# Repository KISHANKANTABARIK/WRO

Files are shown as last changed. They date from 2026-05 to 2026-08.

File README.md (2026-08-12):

# Engineering Documentation - Team DeusMachina

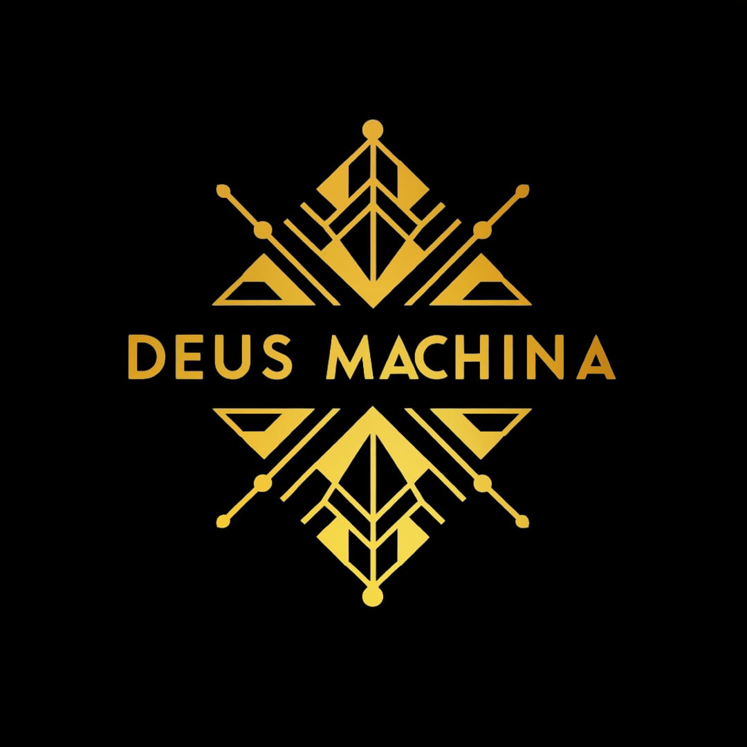
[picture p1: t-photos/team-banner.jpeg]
Team Banner


## Introduction

In this repository you will find all the information related to the construction, design, and programming of the autonomous robot built by *Team DeusMachina* for the  Future Engineers category in the 2026 Season.
This has been an incredible journey with a lot of obstacles, and we have done our best to come up with a design that we were not only satisfied with, but one that could properly accomplish all of the objectives present in this edition of the competition.

## Contents

- [Team Members](#team-members)
- [Hardware Design](#hardware-design)
  * [Design Process](#design-process)
  * [Assembly Process](#assembly-process)
  * [Elements](#elements)
    + [3D Printed](#3d-printed)
    + [Electronics](#electronics)
- [Software Design](#software-design)
  * [Image and Sensor Processing](#image-and-sensor-processing)
    + [Image Capturing](#image-capturing)
    + [Processing Pipeline](#processing-pipeline)
    + [Distance / Position Detection](#distance--position-detection)
  * [Robot Movement](#robot-movement)
    + [Steering / Servo Configuration](#steering--servo-configuration)
    + [Robot Orientation](#robot-orientation)
    + [Route Determination](#route-determination)
  * [Data Sending](#data-sending)
- [Impact](#impact)
- [Our Journey](#our-journey)

---

# Team Members

[#team-members](#team-members)

- **[Kishan Kanta Barik]**:

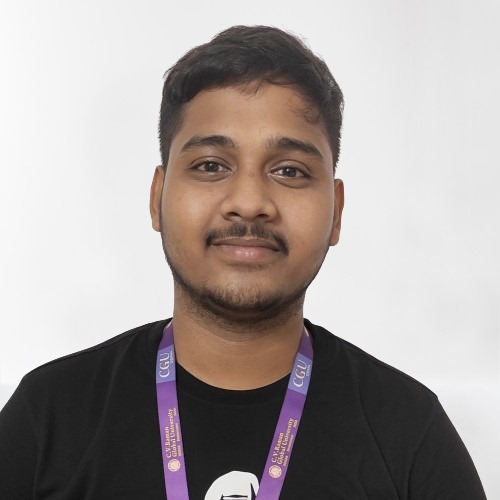
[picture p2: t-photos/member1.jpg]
Member 1 photo

> Hi, my name is Kishan Kanta Barik. I'm part of Team DeusMachina and I'm responsible for ROS2 Architecture & Embedded C . 

- **[Swastik Prasad Behera]**:

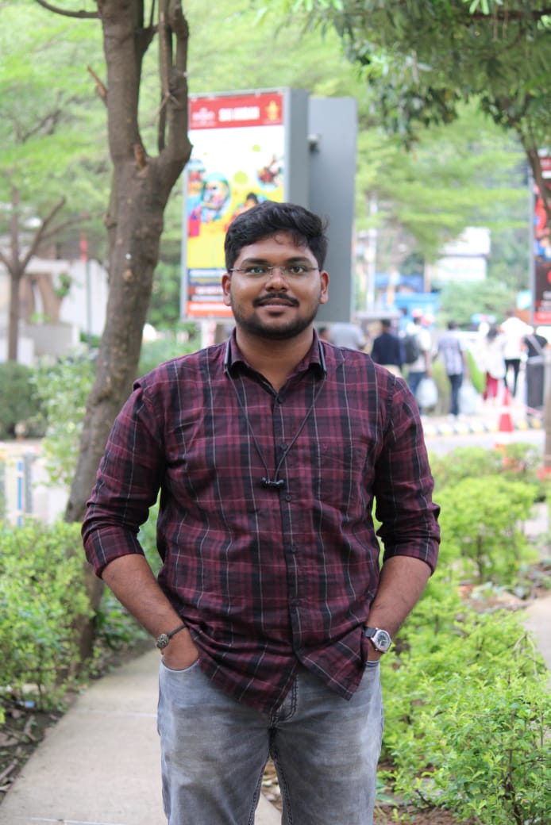
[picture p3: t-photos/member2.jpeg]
Member 2 photo

> Hello, I am Swastik Prasad Behera. I am the team's Designer and I'm responsible for Mechanical Designing and Assembly.

- **[Mohit Kumar Bera]**:

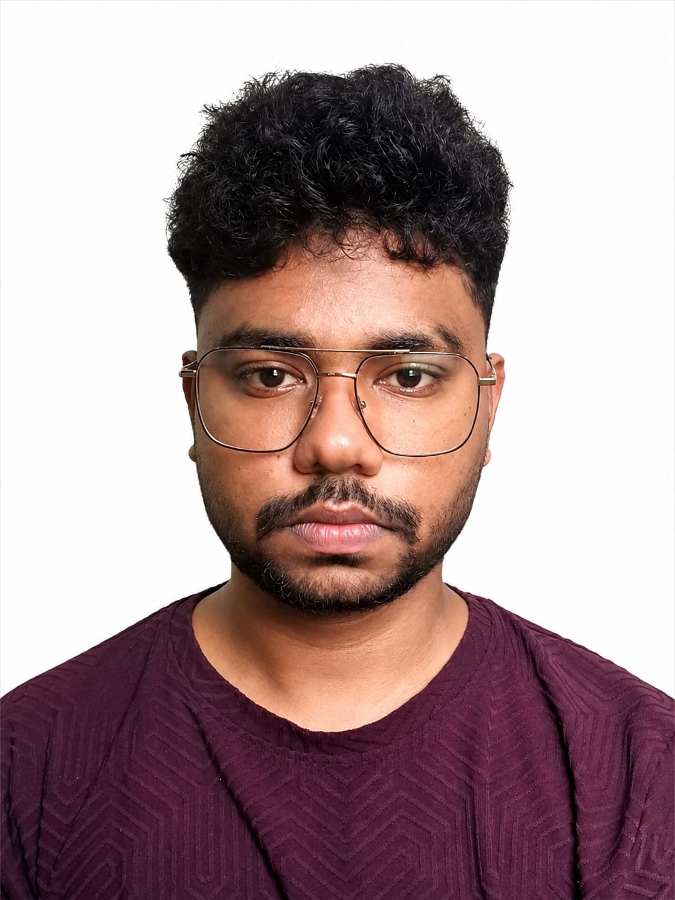
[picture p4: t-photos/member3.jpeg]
Mohit Kumar Bera

> I am Mohit Kumar Bera, the team's Electronics Engineering. I am in charge of Electronics circuits and wiring. 

- **[Achirangshu Patra ]**:

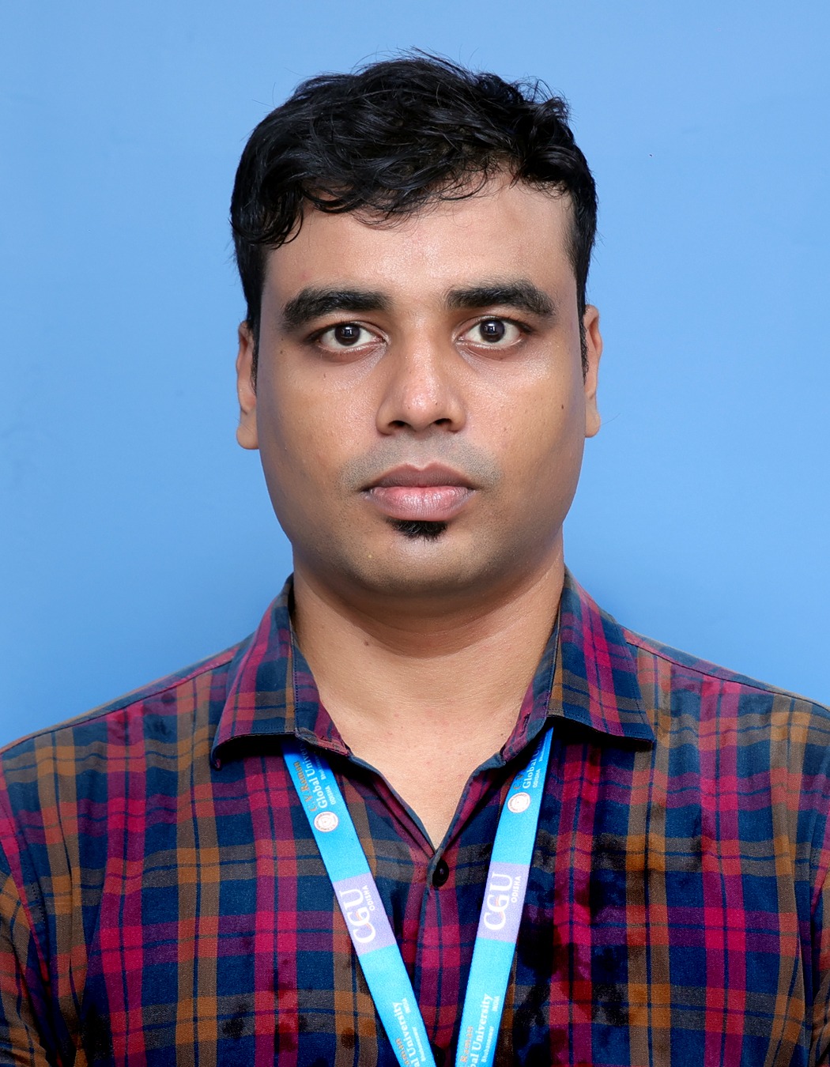
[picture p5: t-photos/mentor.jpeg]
Mentor photo

> Hi, my name is Achirangshu Patra . I have received the B.Tech. degree in Electrical Engineering from Budge Budge Institute of Technology, West Bengal, India, the Post Diploma in Industrial Automation and Robotics from MSME CTTC, Bhubaneswar, India, and the M.Tech. degree in Mechatronics Engineering from C.V. Raman Global University, Odisha, India. He also received the Post Graduate Certificate in Artificial Intelligence and Its Applications under the AICTE QIP program from the Indian Institute of Technology Kharagpur, India. He is currently pursuing the Ph.D. degree in federated unlearning for privacy-preserving machine learning in distributed edge systems at C.V. Raman Global University, where he is also an Assistant Professor and heads the Mitsubishi Electric Authorized Training Centre. He has conducted industrial training and technical workshops for professionals, faculty members, university and school students, covering industrial automation, PLC, HMI, drives, robotics, mechatronics, and Industry 4.0 technologies, with participants from organizations including JPL, JSP, Tata Motors, and other industrial institutions. He has served as a Jury Member for the India Skills National and Regional Competitions and as a WorldSkills Mentor for Industrial Control and Industry 4.0. He also mentors students in various technical competitions and hackathons, including the Mitsubishi Electric Cup, Janatics Automation Skill Challenge, and Smart India Hackathon, supporting students in project development, innovation, and competitive technical skills. His research interests include federated learning, machine unlearning, differential privacy, privacy-preserving edge intelligence, industrial automation, and intelligent cyber-physical systems. 

---

# Hardware Design

## Drivetrain Selection: All-Wheel Drive (4WD) — Single-Motor Dual-Differential System

### Design Overview

Unlike a conventional 4WD setup that uses one motor per axle or per wheel, our robot uses a **single central motor driving all four wheels through a two-differential, single-axle transmission system**. This keeps the drivetrain compact, reduces the number of motors (and therefore the current draw and control complexity), while still delivering torque to all four wheels.

### How the System Works

1. **Motor & Central Gearbox** — A single DC gear motor is mounted in-line with a central gearbox/transfer case (the black housing in the middle of the assembly). This gearbox receives the motor's output and reduces/redirects it into a longitudinal drive path.

2. **Central Driveshaft** — From the gearbox, a single output shaft (the long center driveshaft) runs the length of the chassis, connecting the front and rear ends of the drivetrain. This shaft is what allows one motor to power both axles simultaneously, similar in principle to a propeller shaft in a full-size AWD vehicle.

3. **Dual Differential Units** — At each end of the central driveshaft sits a **bevel-gear differential** (the two purple/magenta gear clusters — one front, one rear). Each differential takes the rotational input from the central shaft and splits it 90° outward to the left and right wheel axles on that end.

4. **Differential Function** — Because each end has its own differential, the left and right wheels on that axle can rotate at slightly different speeds during a turn (standard differential behavior), preventing wheel scrub while still keeping both wheels driven — something a solid/fixed axle can't do.

5. **Half-Shafts to Wheels** — From each differential, a short half-shaft (with a universal/CV-style joint visible in the model) transmits power outward to each wheel hub, ending in a hex adapter for the wheel.

### Why This Configuration

- **Single point of power input** — only one motor needs to be controlled, driven, and powered, which simplifies the motor driver wiring and current budgeting compared to a 4-motor independent-wheel setup.
- **True mechanical AWD** — because power is split at the differential (not electronically per motor), all four wheels stay mechanically synchronized, avoiding the wheel-speed mismatches that can occur with independently controlled motors that aren't perfectly tuned to each other.
- **Weight and space savings** — replacing 3–4 motors with one central motor and a geared/shaft transmission frees up space and mass elsewhere in the chassis for electronics, sensors, and battery placement.
- **Consistent traction front and rear** — since both axles are driven from the same source through matched differentials, torque delivery to the front and rear wheels stays proportional, improving stability under acceleration and through corners.

### Trade-offs

- **Mechanical complexity** — two differentials plus a central driveshaft and multiple universal joints introduce more moving/wearing parts than a single-motor RWD or independent-motor 4WD setup, and require tighter manufacturing/assembly tolerances (gear mesh, shaft alignment).
- **No independent wheel control** — because all wheels are mechanically linked through one motor, the robot cannot apply differential torque electronically (e.g., for skid-steer-style turning assistance); steering must still be handled entirely by the separate front Ackermann steering system.
- **Single point of failure** — if the motor, central gearbox, or driveshaft fails, the entire drivetrain is disabled, unlike a multi-motor 4WD where one motor failure might still leave partial mobility.
- **Assembly precision** — bevel gear differentials need careful backlash tuning; too much play causes drivetrain slop, too little causes binding and excess motor load.

### Comparison with Common WRO Drive Systems

Most WRO Future Engineers teams use one of a handful of drivetrain patterns. Here's how our AWD choice stacks up against the alternatives most commonly seen in the competition:

| Drive System | How it Works | Pros | Cons | Typical WRO Use |
|---|---|---|---|---|
| **Rear-Wheel Drive (RWD)** — *most common in WRO* | A single motor (often a "hex"/gear motor) drives the rear axle; front wheels are steered via a servo through an Ackermann linkage and are not powered. | Simple, lightweight, cheap, few failure points, easy to tune and repair mid-competition. | Less traction on low-grip surfaces or sharp accelerations; all propulsion load falls on two wheels. | The default choice for the large majority of Future Engineers robots, including earlier iterations of our own robot (see [Design Process](#design-process)). |
| **Front-Wheel Drive (FWD)** | A single motor drives the front (steered) axle. | Simplifies packaging when the drive motor and steering share the front module. | Steering geometry becomes more complex (powered + steered wheels); traction can suffer when weight shifts rearward under acceleration. | Rare in WRO — most teams avoid combining steering and driving on the same axle due to added mechanical complexity. |
| **All-Wheel Drive (4WD)** — *our system* | Torque delivered to all four wheels, either through a differential + shaft or independent motors per wheel/axle, while front wheels still steer via Ackermann linkage or independent steering. | Best traction and acceleration consistency; more even load distribution; more resistant to wheel-slip on debris or uneven mats. | Heavier, higher current draw, more complex wiring/mechanical design, more to debug. | Used by a minority of teams, usually those prioritizing consistent lap times over simplicity, or where the track surface/rules reward extra grip. |
| **Skid-Steer / Differential Drive (2WD, no Ackermann)** | Two independently driven wheels (usually rear or side pairs) with passive casters or a fixed axle; turning is achieved by varying wheel speed rather than steering angle. | Mechanically simple, no steering linkage needed, sharp/zero-radius turns possible. | Not Ackermann-compliant, causes wheel scrub, and is generally disallowed or heavily penalized for realism in Future Engineers, which expects car-like steering. | Essentially not used in Future Engineers (more common in other WRO categories like RoboMission); mentioned here only for contrast. |

1. **[Change 1 — e.g. Motor upgrade]**: Explain the problem with the old approach and why the new component/approach was chosen.

Design change 1

2. **[Change 2 — e.g. Wheel replacement]**: Explain the reasoning.

Design change 2

3. **[Change 3 — e.g. Component reorganization]**: Explain the reasoning.

Design change 3

Describe the final architecture (e.g. modular design with distinct functional layers):

> Example: *The final design of the robot is intended as a modular design, consisting of N modules: [module 1 name/purpose], [module 2 name/purpose], [module 3 name/purpose]. This makes it easier to make repairs or replace/rearrange parts.*

Final structure

Link to the full 3D model/CAD files:
[3D design files](./models)

## Assembly Process

Walk through how the robot was physically assembled, module by module or subsystem by subsystem. Include any problems encountered during assembly/testing and how they were solved (e.g. sensor placement issues, interference, structural weaknesses).

Include a wiring/assembly diagram if available:

Assembly diagram

## Elements

### 3D Printed

> **Note:** State your print settings here (material, layer height, infill %, etc.)

- **[Part Name 1]**: Description of its function.

Part 1

- **[Part Name 2]**: Description of its function.

Part 2

- **[Part Name 3]**: Description of its function.

Part 3

*(Add one entry per printed part — chassis, brackets, sensor mounts, covers, etc.)*

### Electronics

For each component, include a short description of its role and a spec box.

- **[Component 1 — e.g. Motor Driver]**: Role in the robot.

Component 1

> **Specifications**
> - Spec 1
> - Spec 2
> - Spec 3

- **[Component 2 — e.g. Drive Motor]**: Role in the robot.

Component 2

> **Specifications**
> - Spec 1
> - Spec 2
> - Spec 3

- **[Component 3 — e.g. Steering Servo]**: Role in the robot.

- **[Component 4 — e.g. Raspberry pi4 - Module B (4GB Ram)]**: Main Micro Processor.

- **[Component 5 — e.g. STM32466RE]**: Secondary microcontroller.

- **[Component 6 — e.g. 2D 360 degree Lidar ]**: To measure and detect the object distance and real time objects.

- **[Component 7 — e.g. Camera]**: Identify the colour of th object.

- **[Component 8 — e.g. Batteries]**: Power source of the vehicle.

*(Add/remove entries to match your actual bill of materials.)*

---

# Software Design

## Image and Sensor Processing

### Image Capturing

Describe how frames/images are captured (camera model, resolution, library used, e.g. OpenCV) and at what stage in the pipeline this happens.

### Processing Pipeline

Describe your detection/processing pipeline step by step (e.g. color space conversion, masking, contour detection). Include representative code snippets:

```python
# Example: HSV threshold values for detection
lower_bound_1 = np.array([H_min, S_min, V_min], np.uint8)
upper_bound_1 = np.array([H_max, S_max, V_max], np.uint8)
```

Processing example

### Distance / Position Detection

Explain how the robot determines distance/position of detected objects relative to itself (e.g. dividing the frame into zones, using sensor fusion, etc.)

Position detection diagram

## Robot Movement

### Steering / Servo Configuration

Describe how the steering mechanism is controlled (pin assignments, control functions/library calls) and how sensor input maps to steering commands.

### Robot Orientation

Describe how the robot determines and maintains its orientation/heading (e.g. based on first detected turn direction, gyroscope, encoders).

### Route Determination

Describe the logic that decides the robot's path (e.g. based on detected color/marker, sensor readings, or map data) and how that decision is communicated between subsystems.

## Data Sending

Describe the communication protocol between your controllers/boards (e.g. I2C, UART, SPI) — include the libraries used, addressing, and wiring (e.g. SDA, SCL, GND for I2C).

```python
# Example: initializing I2C communication
import smbus
bus = smbus.SMBus(1)
I2C_ADDRESS = 0x08
```

---

# Impact

Reflect on the goals of the project, the skills your team developed (technical and non-technical), and the challenges you overcame. This section should convey the learning outcomes and personal/team growth from the project.

---

# Our Journey

Tell your team's story: how you got started, key milestones, competitions attended, results achieved, and what you're aiming for next. This is the narrative/human section of the documentation — make it personal.

---

# Thank You. Team DeusMachina - 2026.

## Repository Structure

```
.
├── models/         # 3D design/CAD files
├── other/          # Miscellaneous supporting files
├── schemes/        # Diagrams, wiring schematics, flowcharts
├── src/            # Source code (robot firmware/software)
├── t-photos/       # Team photos
├── v-photos/       # Vehicle/robot photos
├── videos/         # Demonstration videos
├── README.md       # This file
└── Team-Report_[Competition-Name].pdf   # Official team report
```

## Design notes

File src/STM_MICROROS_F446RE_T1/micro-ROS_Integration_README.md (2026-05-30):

# 🤖 micro-ROS on STM32 (FreeRTOS Node)

> **Bridging a bare-metal FreeRTOS motor controller to a ROS 2 Humble network using micro-ROS and a Raspberry Pi.**

This architecture replaces the raw UART string parser with a native micro-ROS node. The STM32 subscribes directly to ROS 2 topics (`/drive_motor_speed`, `/servo_angle`) and funnels the integers straight into the existing FreeRTOS hardware queues.

---

## 📋 Architecture

```
[ Raspberry Pi 4 ]                 [ STM32 Nucleo-F446RE ]
ROS 2 Humble                       FreeRTOS + micro-ROS

$ ros2 topic pub ────(USB)────> [ it_transport.c ] ──> [ microROS_Task ]
/drive_motor_speed                                         │
                                                           ├──> [ DCQueue ]
                                                           └──> [ ServoQueue ]
```

## 🛠️ Critical CubeMX Configurations

To prevent the STM32 from freezing on boot when running micro-ROS, these specific settings must be applied in `.ioc`:

1. **SysTick Conflict:** FreeRTOS must use `TIM1` as its Timebase Source (System Core -> SYS).
2. **Memory Starvation:** The `microROS_Task` stack size must be increased from 128 words to **`3000`** words (Middleware -> FREERTOS).
3. **Interrupt Transport:** `USART2 global interrupt` MUST be checked in the NVIC settings to allow the Pi to handshake with the STM32.

---

## 🚨 Integration Challenges & Fixes

### 1. Linker Error: "Multiple Definition of..."
* **Cause:** Copying `it_transport.c` or memory allocator `.c` files directly into `Core/Src` while simultaneously telling the compiler to build the `extra_sources` folder. The compiler builds two copies of the same functions.
* **Fix:** Delete the duplicates from `Core/Src`. Ensure you only unlock the `extra_sources` folder and uncheck "Exclude from build" for `it_transport.c` specifically.

### 2. Phantom Error: "Build Failed" (But the .elf is generated)
* **Cause:** The Eclipse-based IDE misinterprets a standard warning (`_gettimeofday is not implemented`) as a fatal error.
* **Fix:** If the `arm-none-eabi-size` table prints in the console showing the memory footprint, the code **did** compile successfully. Ignore the "Build Failed" text and flash the board.

### 3. Agent Stuck on "running..." (No Session Established)
* **Cause A (Handshake Timeout):** The STM32 booted too fast and the Pi was not ready, or the ping timeout was too aggressive.
  * **Fix:** Change the ping loop to `rmw_uros_ping_agent(1000, 1)` (1000ms timeout). Press the physical **RESET** button on the STM32 *after* the agent says `running...`.
* **Cause B (Missing Allocators):** FreeRTOS crashed because micro-ROS tried to use standard `malloc()`.
  * **Fix:** Ensure the custom allocators (`microros_allocate`, etc.) are defined and linked via `rcutils_set_default_allocator(&freeRTOS_allocator);` before the ping loop starts.

### 4. Agent Crash: "Serial Port Not Found, Error 2"
* **Cause:** You pressed the RESET button on the Nucleo board while the Agent was actively streaming data. This briefly cuts power to the ST-Link USB chip, causing Linux to lose the `/dev/ttyACM0` mount.
* **Fix:** Restart the Agent command on the Pi.

## 🚀 Running the Node

1. Flash the STM32 and plug it into the Pi via USB.
2. On the Pi, source the workspace: `source ~/microros_ws/install/local_setup.bash`
3. Start the agent: `ros2 run micro_ros_agent micro_ros_agent serial --dev /dev/ttyACM0 -b 115200 -v6`
4. Press RESET on the STM32. Wait for `Session established`.
5. In a new terminal, drive the robot:
   `ros2 topic pub --once /drive_motor_speed std_msgs/msg/Int32 "{data: 25000}"`

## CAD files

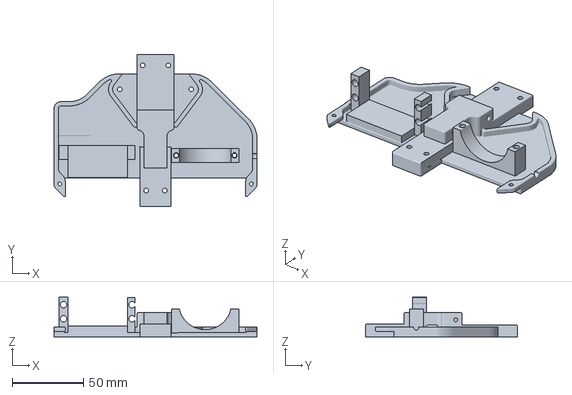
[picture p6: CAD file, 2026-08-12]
models/Chassis/chassis-front.3mf
142.4 x 106.8 x 28.0 mm

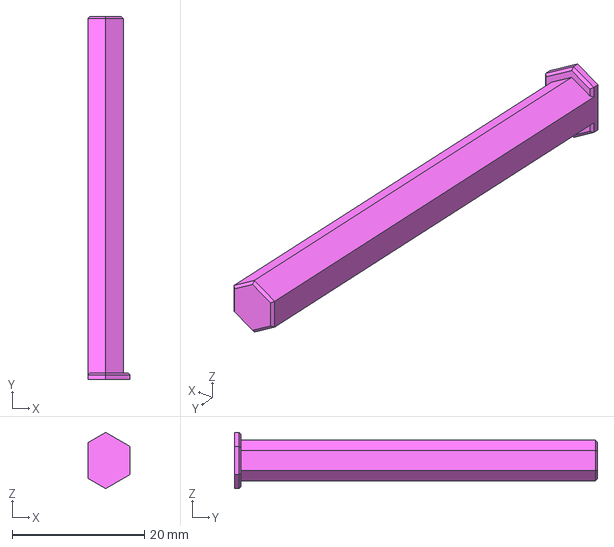
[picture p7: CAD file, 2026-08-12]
models/Drive/Center/center-shaft-rear.3mf
6.37 x 54.9 x 8.51 mm

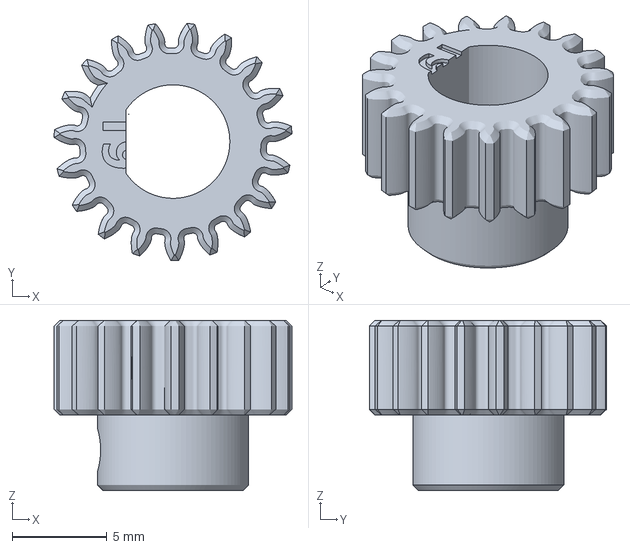
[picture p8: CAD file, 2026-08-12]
models/Drive/Center/Gears/pinion-06module-19T.3mf
12.6 x 12.6 x 9.00 mm

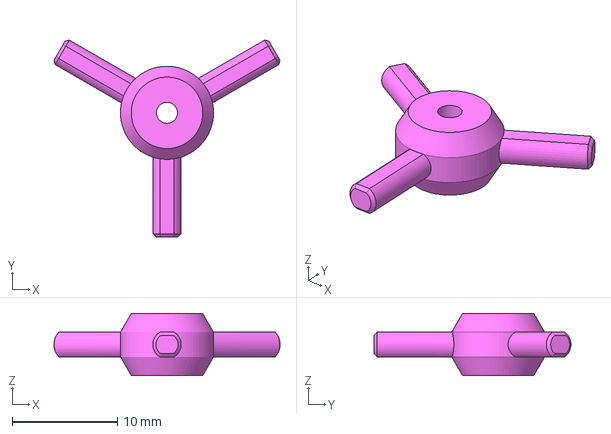
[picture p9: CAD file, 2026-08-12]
models/Drive/Differential Unit Front/Differential Gears/diff-gear-shaft.3mf
21.5 x 18.7 x 5.90 mm

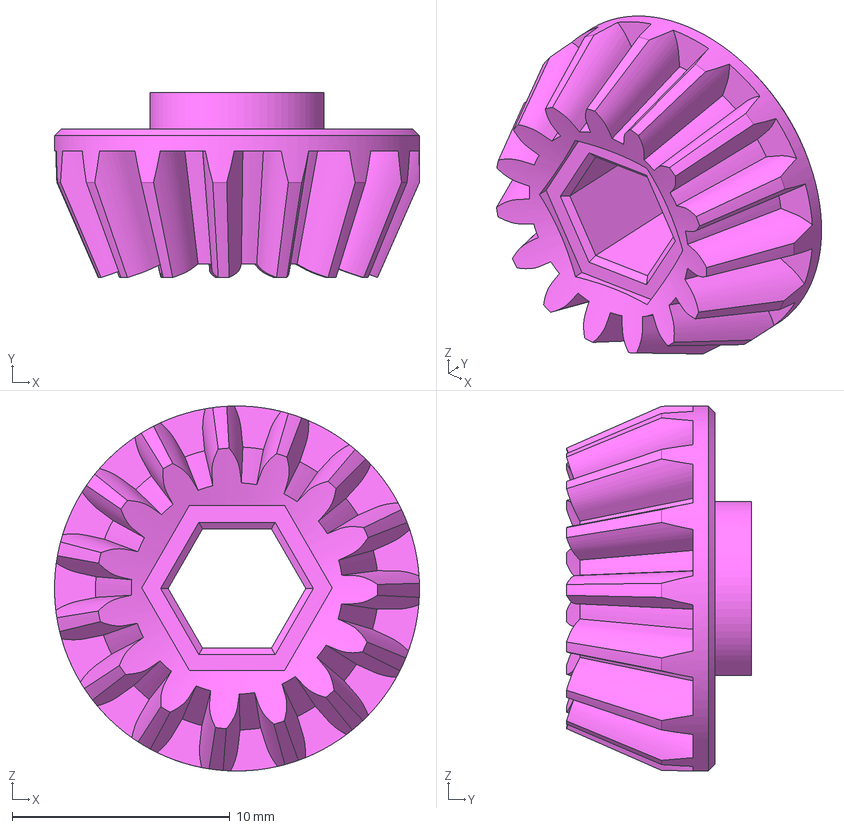
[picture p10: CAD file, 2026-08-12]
models/Drive/Differential Unit Front/Drive Gear/drive-gear-A.3mf
16.7 x 8.49 x 16.7 mm

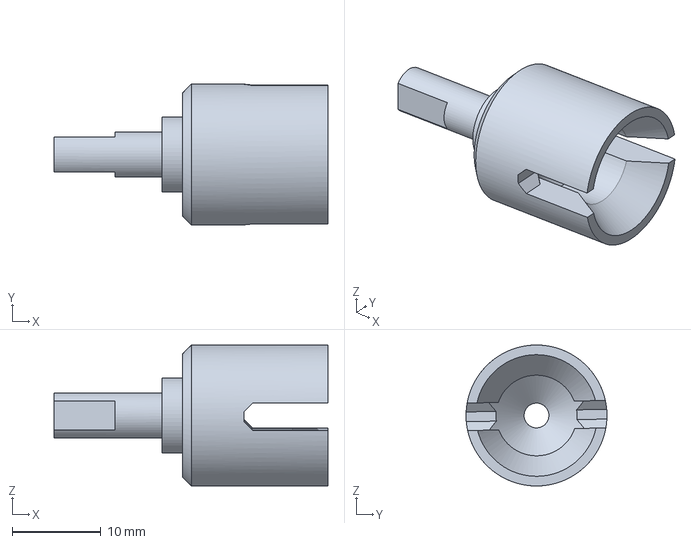
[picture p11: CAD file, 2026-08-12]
models/Drive/Differential Unit Front/Driver Cup/drive-cup-A.3mf
30.9 x 15.9 x 15.9 mm

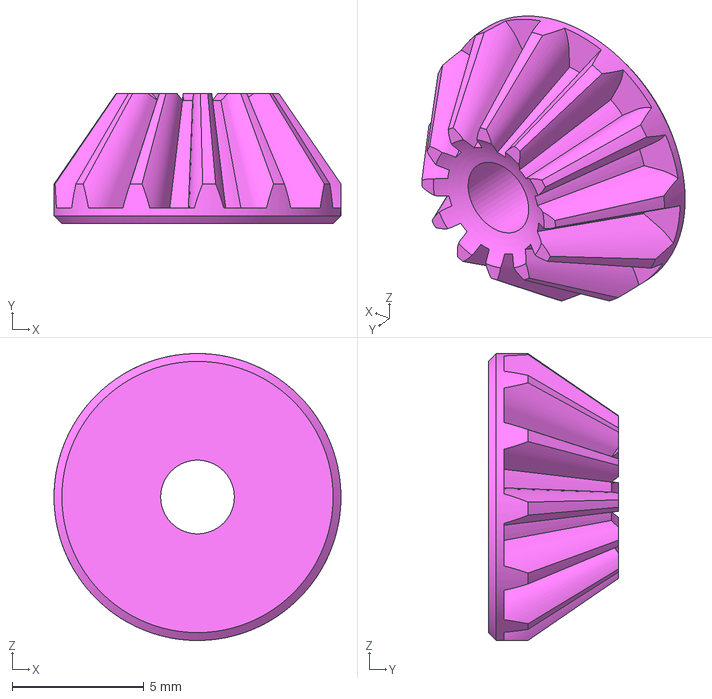
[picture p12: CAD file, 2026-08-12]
models/Drive/Differential Unit Rear/Differential Unit/diff-gear-C_2.3mf
10.9 x 4.95 x 10.9 mm

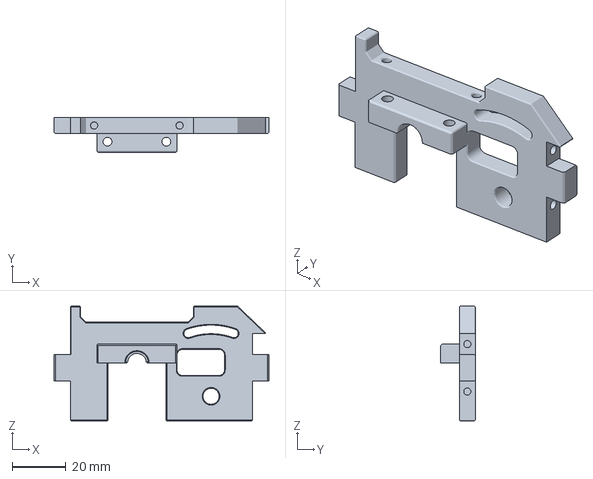
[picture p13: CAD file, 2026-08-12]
models/Drive/Motor Mount/motor-mount-B.3mf
80.4 x 13.0 x 42.9 mm

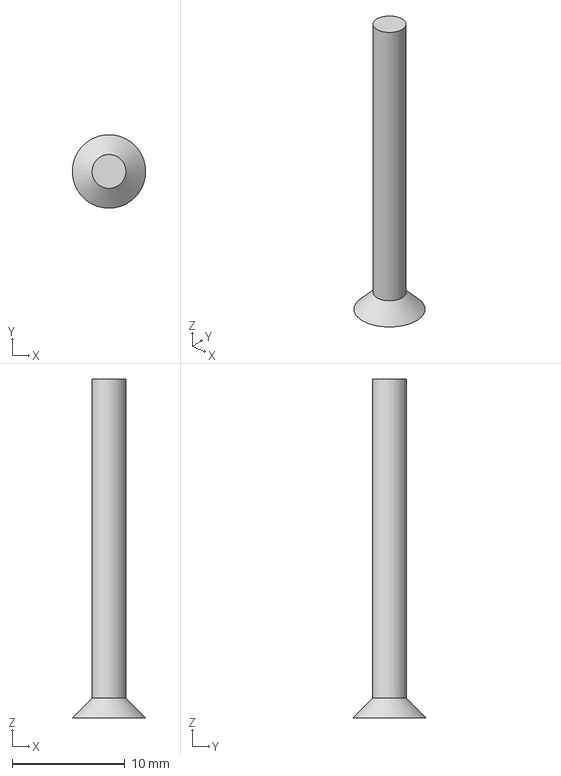
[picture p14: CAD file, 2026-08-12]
models/Drive/Wheel Axle Unit_4_units/FHCS-M3-30.3mf
6.50 x 6.50 x 30.0 mm

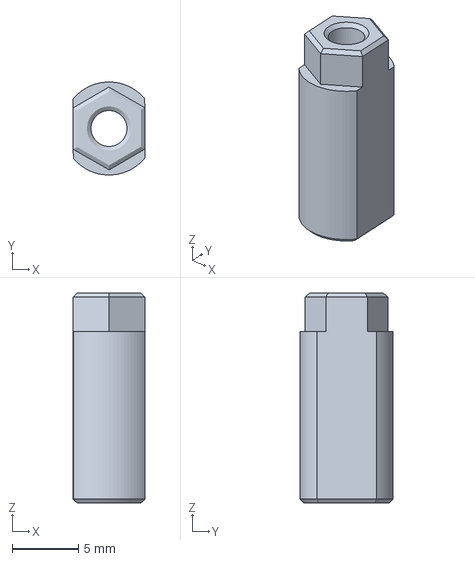
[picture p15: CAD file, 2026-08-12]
models/Front Assymble/Front Gearbox/front-steering-arm-post.3mf
5.42 x 7.00 x 15.8 mm

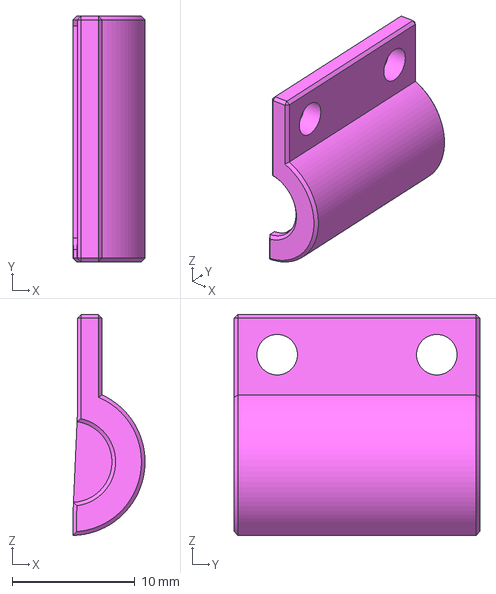
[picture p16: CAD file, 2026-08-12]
models/Front Assymble/Front Suspension/ESE Rotary Dampers/ese-rotary-damper-R-B2.3mf
5.88 x 20.0 x 18.0 mm

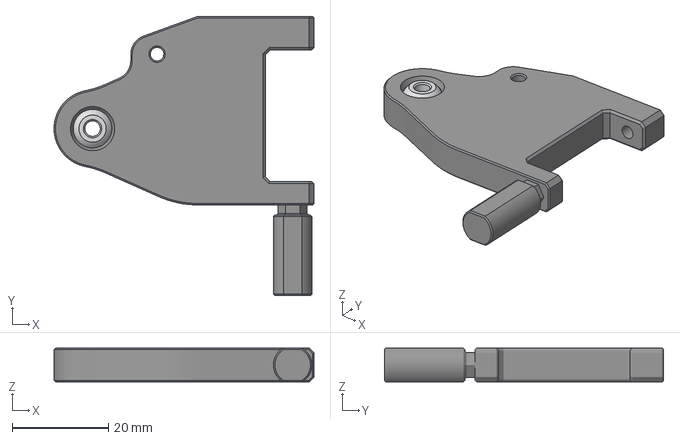
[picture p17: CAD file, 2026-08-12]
models/Front Assymble/Front Suspension/Front Suspension Lower/front-sus-lower-arm-A (Print_2).3mf
53.9 x 57.9 x 7.00 mm

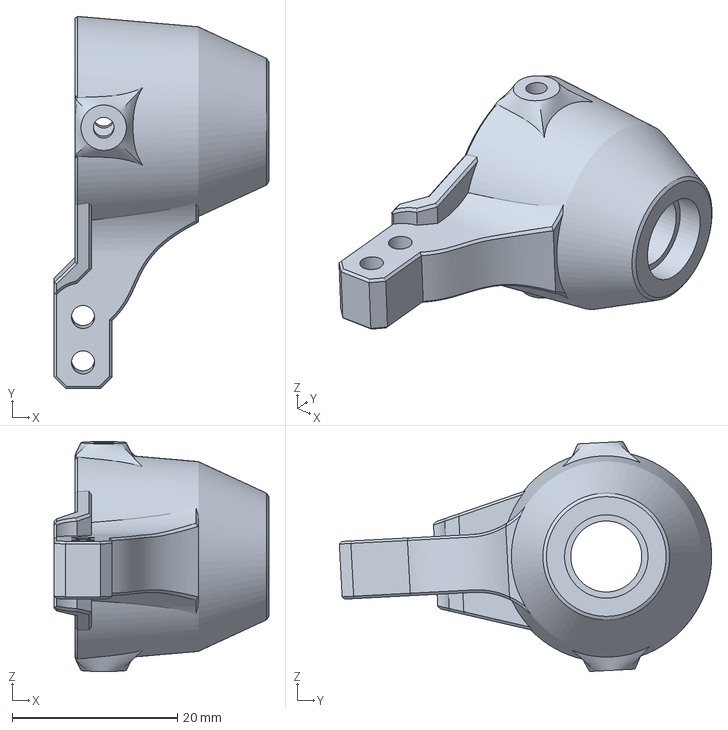
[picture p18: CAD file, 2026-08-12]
models/Front Assymble/Front Suspension/Front Suspension Uplight_Print_2_Each/front-sus-uplight.3mf
26.0 x 45.1 x 27.8 mm

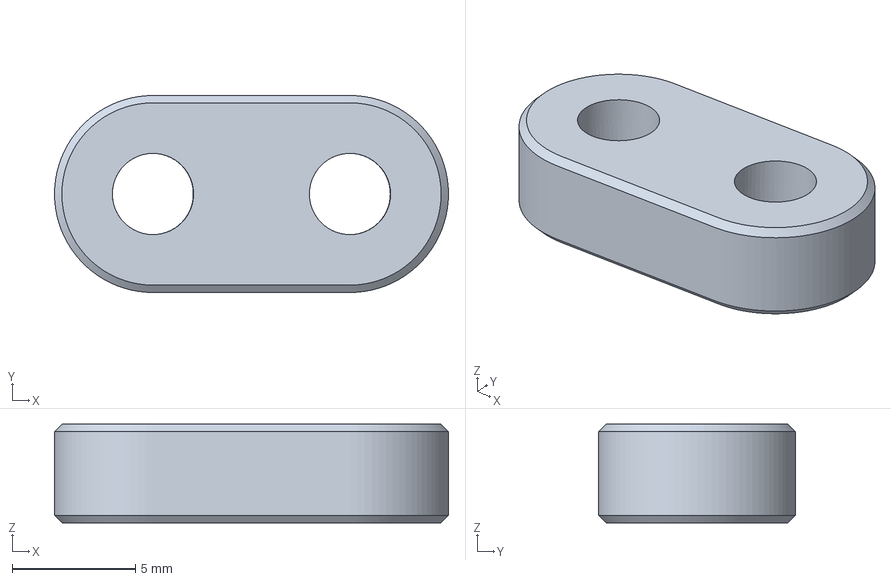
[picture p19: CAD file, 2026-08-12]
models/Front Assymble/Front Suspension/Leaf Spring/leaf-spring-spacer-4mm.3mf
16.0 x 8.00 x 4.00 mm

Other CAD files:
models/Front Assymble/Front Suspension/Upper Arm_ (Print Each 2)/upper-arm-A.3mf
models/Front Assymble/front-body-mount-A.3mf
models/Motor Mount/MOTOR_MOUNT2.3mf
models/Rear Assymble/Rear Gearbox/rear-gearbox-upper.3mf
models/Chassis/chassis-rear.3mf
models/Drive/Center/Gears/spar-06module-70T-A.3mf
models/Drive/Center/Gears/spar-spacer.3mf
models/Drive/Center/center-shaft-front.3mf
models/Drive/Center/center-shaft.3mf
models/Drive/Center/cup-drive-cup-front.3mf
models/Drive/Center/cup-drive-cup.3mf
models/Drive/Differential Unit Front/Differential Gears/diff-gear-A.3mf
models/Drive/Differential Unit Front/Differential Gears/diff-gear-B.3mf
models/Drive/Differential Unit Front/Differential Gears/diff-gear-B_2.3mf
models/Drive/Differential Unit Front/Differential Gears/diff-gear-C.3mf
models/Drive/Differential Unit Front/Differential Gears/diff-gear-C_2.3mf
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

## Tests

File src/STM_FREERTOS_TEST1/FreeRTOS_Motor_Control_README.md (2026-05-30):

# 🤖 STM32 Bare-Metal Robotics Control (FreeRTOS + HAL)

> **Real-time dual-motor control architecture using FreeRTOS message queues and hardware PWM on an STM32 Nucleo-F446RE.**

This README covers the base embedded implementation for controlling a high-current DC motor (via a BTS7960 driver) and a standard PWM servo using an event-driven RTOS architecture.

---

## 📋 Architecture Overview

This project separates hardware control from communication logic using FreeRTOS queues.

```
[ UART ISR ] ──> (Thread Flag) ──> [ UART_Task ]
                                         │
                                         ├──> [ DCQueue ] ──> [ DCMotor_Task ] ──> (TIM3 PWM)
                                         │
                                         └──> [ ServoQueue ] ──> [ Servo_Task ] ──> (TIM4 PWM)
```

## 🛠️ Hardware Setup

| Component | STM32 Pin | Timer/Channel | Notes |
| :--- | :--- | :--- | :--- |
| **DC Motor PWM (BTS7960)** | `PB4` | TIM3_CH1 | 65535 Max Period |
| **DC Motor DIR_L** | `PA11` | GPIO Output | |
| **DC Motor DIR_R** | `PA12` | GPIO Output | |
| **Servo PWM** | `PB6` | TIM4_CH1 | 50Hz (20ms) Period |
| **UART RX** | `PA3` (USART2) | ISR / IT | 115200 Baud |

### Important Power Warning (The Jumper Burnout)
If you are powering the STM32 from a heavy external 5V/12V source (like an LM2596 buck converter tied to a motor battery), you **MUST** move the `JP5` jumper on the Nucleo board from `U5V` to `E5V`.
* **Risk:** If `JP5` is left on `U5V`, the external battery will back-feed into the laptop's USB port, triggering an overcurrent shutdown or frying the ST-Link controller on the board.

---

## 🚨 Known Issues & Troubleshooting

### 1. Serial Monitor Shows Garbage or Nothing
* **Cause:** The `HAL_UART_Receive_IT` needs to be "primed" before the OS kernel starts.
* **Fix:** Ensure `HAL_UART_Receive_IT(&huart2, &rx_byte, 1);` is called in `main.c` right before `osKernelInitialize();`. Ensure the ISR callback re-arms the interrupt.

### 2. Servo Jitters or Moves Erratically
* **Cause:** The Timer Prescaler/Period is mathematically incorrect for 50Hz, or the map logic is outputting floats instead of integers.
* **Fix:** For a 50Hz signal on an 84MHz clock: Prescaler = `84-1`, Period = `20000-1`.
  * The angle calculation must be integer-safe: `1000 + ((angle * 1000) / 180)`.

### 3. Board Becomes Unresponsive / PC Does Not Detect USB
* **Cause:** A high-voltage short circuit (e.g., multimeter probe slipping) pushed 12V back into the STM32 logic pins, destroying the ST-Link chip's USB data lines.
* **Fix:** The ST-Link is dead. You must use an external USB-to-TTL serial adapter on pins `PA2/PA3` to read the monitor, or replace the Nucleo board.

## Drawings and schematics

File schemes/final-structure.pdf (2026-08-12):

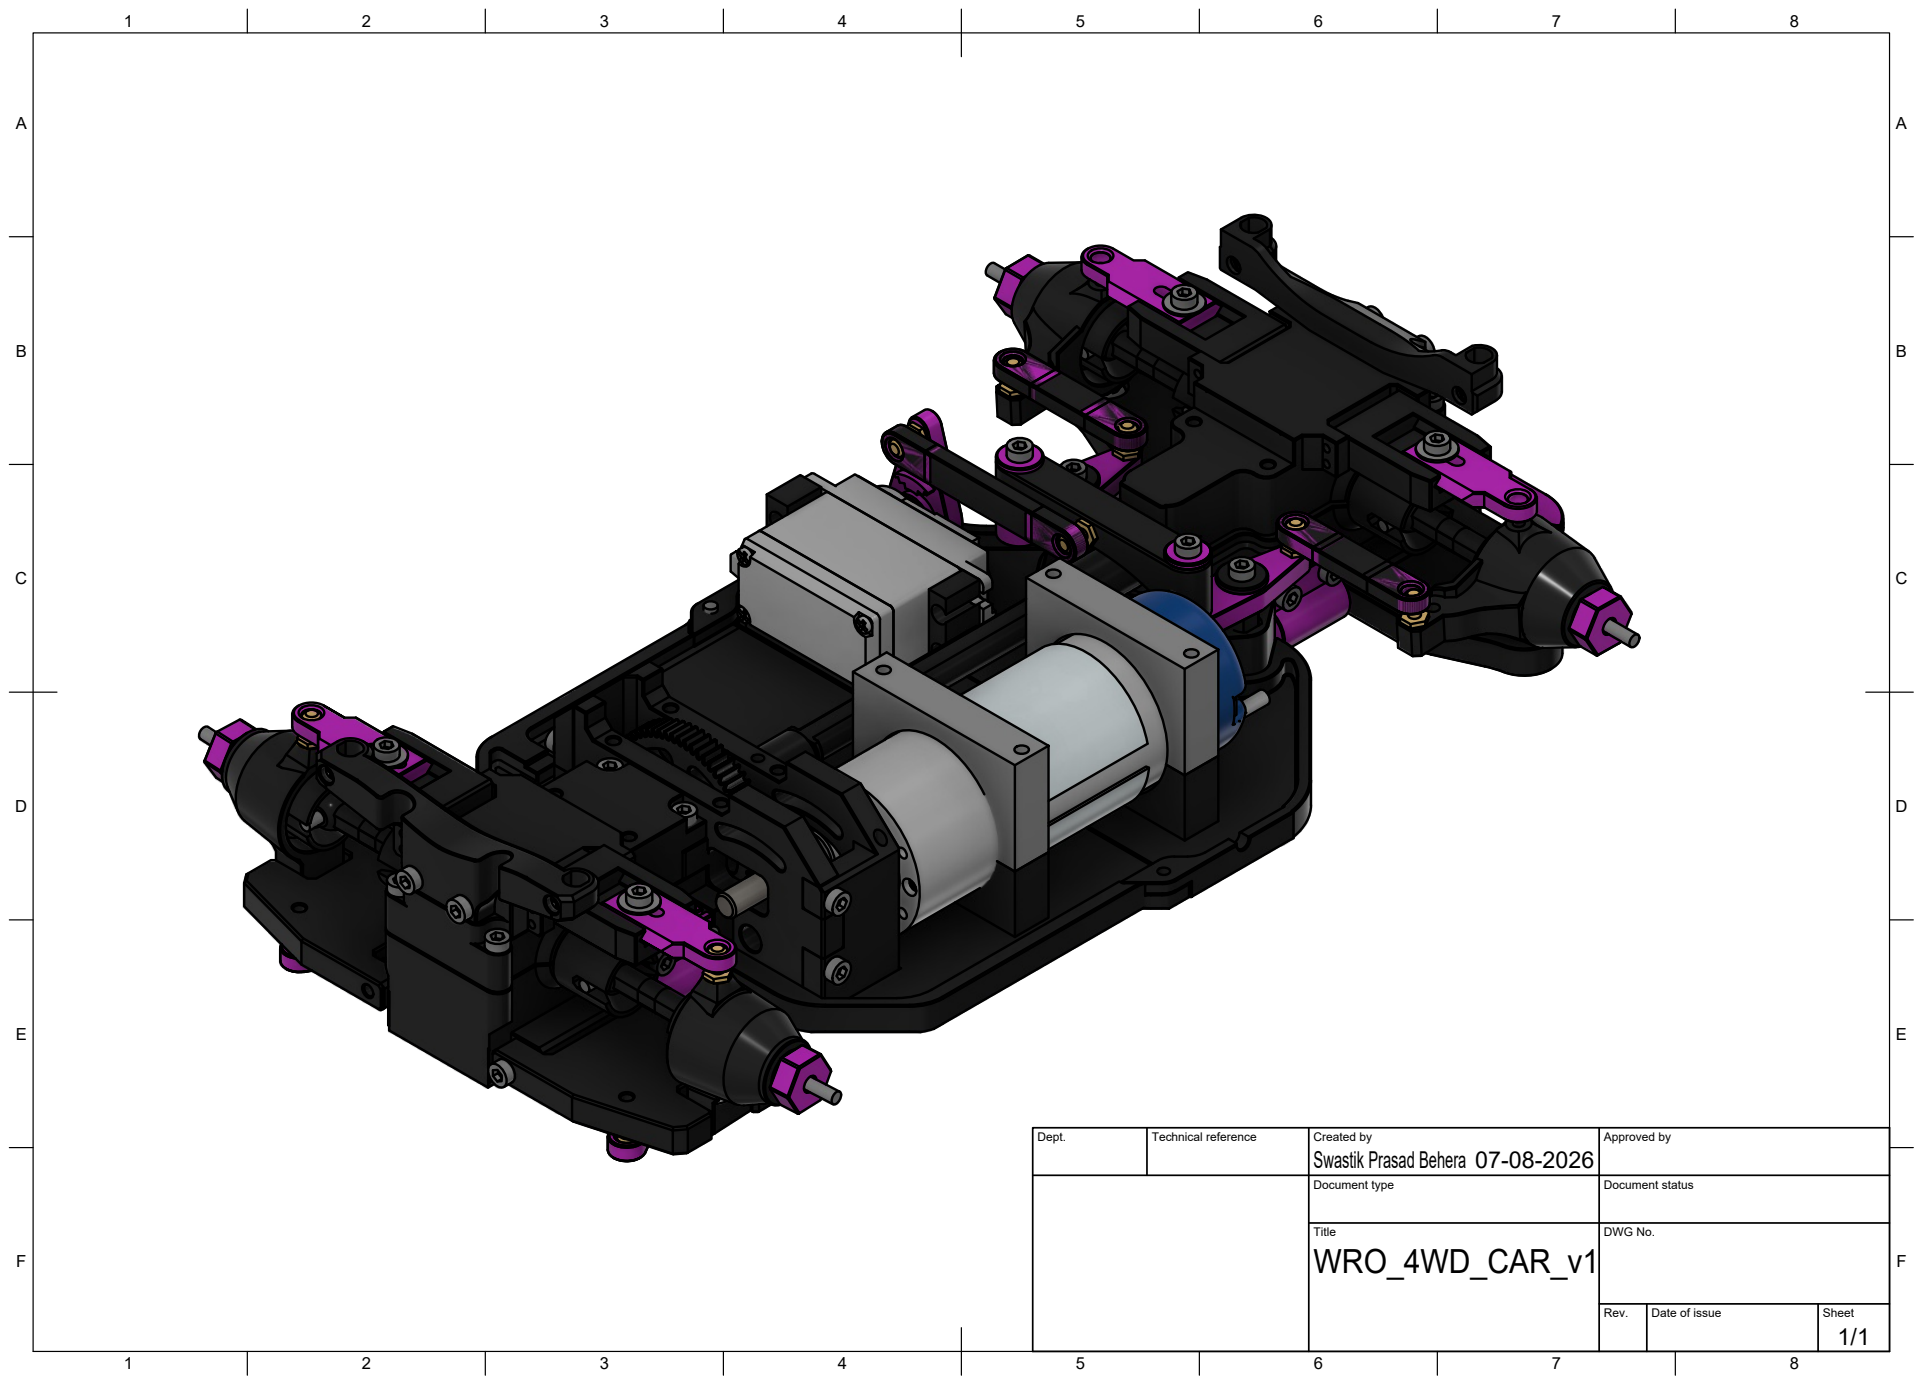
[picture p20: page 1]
Title; DWG No.; Rev.; Date of issue; Sheet

Dept. | Technical reference | Created by Swastik Prasad Behera 07-08-2026 | Approved by

Document type | Document status

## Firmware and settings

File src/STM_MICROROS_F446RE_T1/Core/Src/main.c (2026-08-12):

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
/* Includes ------------------------------------------------------------------*/
#include "main.h"
#include "cmsis_os.h"

/* USER CODE BEGIN Includes */
#include <stdio.h>
#include <string.h>
#include <stdlib.h>  // ADD THIS for atoi()
/* USER CODE END Includes */

TIM_HandleTypeDef htim2;
TIM_HandleTypeDef htim3;
TIM_HandleTypeDef htim4;

UART_HandleTypeDef huart2;
DMA_HandleTypeDef hdma_usart2_rx;
DMA_HandleTypeDef hdma_usart2_tx;

/* Definitions for UART_Task */
osThreadId_t UART_TaskHandle;
const osThreadAttr_t UART_Task_attributes = {
  .name = "UART_Task",
  .stack_size = 128 * 4,
  .priority = (osPriority_t) osPriorityNormal,
};
/* Definitions for DCMotor_Task */
osThreadId_t DCMotor_TaskHandle;
const osThreadAttr_t DCMotor_Task_attributes = {
  .name = "DCMotor_Task",
  .stack_size = 128 * 4,
  .priority = (osPriority_t) osPriorityBelowNormal,
};
/* Definitions for Servo_Task */
osThreadId_t Servo_TaskHandle;
const osThreadAttr_t Servo_Task_attributes = {
  .name = "Servo_Task",
  .stack_size = 128 * 4,
  .priority = (osPriority_t) osPriorityBelowNormal1,
};
/* Definitions for microROS_Task */
osThreadId_t microROS_TaskHandle;
const osThreadAttr_t microROS_Task_attributes = {
  .name = "microROS_Task",
  .stack_size = 3000 * 4,
  .priority = (osPriority_t) osPriorityNormal,
};
/* Definitions for DCQueue */
osMessageQueueId_t DCQueueHandle;
const osMessageQueueAttr_t DCQueue_attributes = {
  .name = "DCQueue"
};
/* Definitions for ServoQueue */
osMessageQueueId_t ServoQueueHandle;
const osMessageQueueAttr_t ServoQueue_attributes = {
  .name = "ServoQueue"
};
/* USER CODE BEGIN PV */
uint8_t rx_byte; // Global variable for UART buffer
/* USER CODE END PV */

void SystemClock_Config(void);
static void MX_GPIO_Init(void);
static void MX_DMA_Init(void);
static void MX_USART2_UART_Init(void);
static void MX_TIM2_Init(void);
static void MX_TIM3_Init(void);
static void MX_TIM4_Init(void);
void UART_Task_Start(void *argument);
void DCMotor_Task_Start(void *argument);
void Servo_Task_Start(void *argument);
void microROS_StartTask(void *argument);

/**
  * @brief  The application entry point.
  * @retval int
  */
int main(void)
{

  /* MCU Configuration--------------------------------------------------------*/

  /* Reset of all peripherals, Initializes the Flash interface and the Systick. */
  HAL_Init();

  /* Configure the system clock */
  SystemClock_Config();

  /* Initialize all configured peripherals */
  MX_GPIO_Init();
  MX_DMA_Init();
  MX_USART2_UART_Init();
  MX_TIM2_Init();
  MX_TIM3_Init();
  MX_TIM4_Init();
  /* USER CODE BEGIN 2 */
  HAL_TIM_PWM_Start(&htim3, TIM_CHANNEL_1);       // RPWM
  HAL_TIM_PWM_Start(&htim3, TIM_CHANNEL_2);   	  // LPWM
  HAL_TIM_PWM_Start(&htim4, TIM_CHANNEL_1);       // Servo Motor PWM
  HAL_TIM_Encoder_Start(&htim2, TIM_CHANNEL_ALL); // Encoder Timer


  // Enable BTS7960 only now — RPWM/LPWM are already actively driven
  // at 0% duty cycle by the timer, so the motor cannot move.
  HAL_GPIO_WritePin(GPIOA, DIR1_Pin|DIR2_Pin, GPIO_PIN_SET);

//  HAL_UART_Receive_IT(&huart2, &rx_byte, 1);      // Prime the UART interrupt
  /* USER CODE END 2 */

  /* Init scheduler */
  osKernelInitialize();

  /* USER CODE BEGIN RTOS_MUTEX */
  /* add mutexes, ... */
  /* USER CODE END RTOS_MUTEX */

  /* USER CODE BEGIN RTOS_SEMAPHORES */
  /* add semaphores, ... */
  /* USER CODE END RTOS_SEMAPHORES */

  /* USER CODE BEGIN RTOS_TIMERS */
  /* start timers, add new ones, ... */
  /* USER CODE END RTOS_TIMERS */

  /* Create the queue(s) */
  /* creation of DCQueue */
  DCQueueHandle = osMessageQueueNew (16, sizeof(int16_t), &DCQueue_attributes);

  /* creation of ServoQueue */
  ServoQueueHandle = osMessageQueueNew (16, sizeof(uint16_t), &ServoQueue_attributes);

  /* USER CODE BEGIN RTOS_QUEUES */
  /* add queues, ... */
  /* USER CODE END RTOS_QUEUES */

  /* Create the thread(s) */
  /* creation of UART_Task */
  UART_TaskHandle = osThreadNew(UART_Task_Start, NULL, &UART_Task_attributes);

  /* creation of DCMotor_Task */
  DCMotor_TaskHandle = osThreadNew(DCMotor_Task_Start, NULL, &DCMotor_Task_attributes);

  /* creation of Servo_Task */
  Servo_TaskHandle = osThreadNew(Servo_Task_Start, NULL, &Servo_Task_attributes);

  /* creation of microROS_Task */
  microROS_TaskHandle = osThreadNew(microROS_StartTask, NULL, &microROS_Task_attributes);

  /* USER CODE BEGIN RTOS_THREADS */
  /* add threads, ... */
  /* USER CODE END RTOS_THREADS */

  /* USER CODE BEGIN RTOS_EVENTS */
  /* add events, ... */
  /* USER CODE END RTOS_EVENTS */

  /* Start scheduler */
  osKernelStart();

  /* We should never get here as control is now taken by the scheduler */

  /* Infinite loop */
  /* USER CODE BEGIN WHILE */
  while (1)
  {
    /* USER CODE END WHILE */

    /* USER CODE BEGIN 3 */
  }
  /* USER CODE END 3 */
}

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
/* USER CODE BEGIN Header_UART_Task_Start */
/**
  * @brief  Function implementing the UART_Task thread.
  * @param  argument: Not used
  * @retval None
  */
/* USER CODE END Header_UART_Task_Start */
void UART_Task_Start(void *argument)
{
  /* USER CODE BEGIN 5 */
  for(;;)
  {
      osDelay(osWaitForever); // Safely disable this old task
  }
  /* USER CODE END 5 */
}

/* USER CODE BEGIN Header_DCMotor_Task_Start */
/**
* @brief Function implementing the DCMotor_Task thread.
*/
/* USER CODE END Header_DCMotor_Task_Start */
void DCMotor_Task_Start(void *argument)
{
  /* USER CODE BEGIN DCMotor_Task_Start */
  int16_t target_speed;
  /* Infinite loop */
  for(;;)
  {
      // Block until new speed arrives
      if (osMessageQueueGet(DCQueueHandle, &target_speed, NULL, osWaitForever) == osOK) {
          if (target_speed >= 0) {
              __HAL_TIM_SET_COMPARE(&htim3, TIM_CHANNEL_1, target_speed);   // RPWM
              __HAL_TIM_SET_COMPARE(&htim3, TIM_CHANNEL_2, 0);              // LPWM off
          } else {
              __HAL_TIM_SET_COMPARE(&htim3, TIM_CHANNEL_1, 0);              // RPWM off
              __HAL_TIM_SET_COMPARE(&htim3, TIM_CHANNEL_2, -target_speed);  // LPWM
          }
      }
  }
  /* USER CODE END DCMotor_Task_Start */
}

/* USER CODE BEGIN Header_Servo_Task_Start */
/**
* @brief Function implementing the Servo_Task thread.
* @param argument: Not used
* @retval None
*/
/* USER CODE END Header_Servo_Task_Start */
void Servo_Task_Start(void *argument)
{
  /* USER CODE BEGIN Servo_Task_Start */
	uint16_t target_angle;
  /* Infinite loop */
  for(;;)
  {
  if (osMessageQueueGet(ServoQueueHandle, &target_angle, NULL, osWaitForever) == osOK) {

		  // Map 0-180 degrees to 1000-2000 microseconds (assuming 1us timer ticks)
		  uint32_t pulse_width = 1000 + ((target_angle * 1000) / 180);

		  __HAL_TIM_SET_COMPARE(&htim4, TIM_CHANNEL_1, pulse_width);
	  }
    osDelay(1);
  }
  /* USER CODE END Servo_Task_Start */
}

/* USER CODE BEGIN Header_microROS_StartTask */
/**
* @brief Function implementing the microROS_Task thread.
* @param argument: Not used
* @retval None
*/
/* USER CODE END Header_microROS_StartTask */
void microROS_StartTask(void *argument)
{
  /* USER CODE BEGIN microROS_StartTask */
  // Expose the function we wrote in freertos.c
  extern void StartMicroROSTask(void *argument);

  // Jump over to freertos.c and run the ROS loop FIRST!
  StartMicroROSTask(NULL);

  /* Infinite loop (Fallback only, it should never reach here) */
  for(;;)
  {
    osDelay(1);
  }
  /* USER CODE END microROS_StartTask */
}

/**
  * @brief  Period elapsed callback in non blocking mode
  * @note   This function is called  when TIM6 interrupt took place, inside
  * HAL_TIM_IRQHandler(). It makes a direct call to HAL_IncTick() to increment
  * a global variable "uwTick" used as application time base.
  * @param  htim : TIM handle
  * @retval None
  */
void HAL_TIM_PeriodElapsedCallback(TIM_HandleTypeDef *htim)
{
  if (htim->Instance == TIM6)
  {
    HAL_IncTick();
  }
}

/**
  * @brief  This function is executed in case of error occurrence.
  * @retval None
  */
void Error_Handler(void)
{
  /* USER CODE BEGIN Error_Handler_Debug */
  /* User can add his own implementation to report the HAL error return state */
  __disable_irq();
  while (1)
  {
  }
  /* USER CODE END Error_Handler_Debug */
}
#ifdef USE_FULL_ASSERT
/**
  * @brief  Reports the name of the source file and the source line number
  *         where the assert_param error has occurred.
  * @param  file: pointer to the source file name
  * @param  line: assert_param error line source number
  * @retval None
  */
void assert_failed(uint8_t *file, uint32_t line)
{
  /* USER CODE BEGIN 6 */
  /* User can add his own implementation to report the file name and line number,
     ex: printf("Wrong parameters value: file %s on line %d\r\n", file, line) */
  /* USER CODE END 6 */
}
#endif /* USE_FULL_ASSERT */

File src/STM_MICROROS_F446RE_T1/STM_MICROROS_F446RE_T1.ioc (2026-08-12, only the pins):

Mcu.UserName=STM32F446RETx
PA0-WKUP.Signal=S_TIM2_CH1_ETR
PA1.Signal=S_TIM2_CH2
PA11.GPIO_Label=DIR1
PA11.Signal=GPIO_Output
PA12.GPIO_Label=DIR2
PA12.Signal=GPIO_Output
PA13.GPIO_Label=TMS
PA13.Signal=SYS_JTMS-SWDIO
PA14.GPIO_Label=TCK
PA14.Signal=SYS_JTCK-SWCLK
PA2.Signal=USART2_TX
PA3.Signal=USART2_RX
PA5.GPIO_Label=LD2 [Green Led]
PA5.Signal=GPIO_Output
PA6.GPIO_Label=R_PWM
PA6.Signal=S_TIM3_CH1
PA7.GPIO_Label=L_PWM
PA7.Signal=S_TIM3_CH2
PB3.GPIO_Label=SWO
PB3.Signal=SYS_JTDO-SWO
PB6.GPIO_Label=SERVO_PWM
PB6.Signal=S_TIM4_CH1
PC13.GPIO_Label=B1 [Blue PushButton]
PC13.Signal=GPXTI13
PC14-OSC32_IN.Signal=RCC_OSC32_IN
PC15-OSC32_OUT.Signal=RCC_OSC32_OUT
PH0-OSC_IN.Signal=RCC_OSC_IN
PH1-OSC_OUT.Signal=RCC_OSC_OUT

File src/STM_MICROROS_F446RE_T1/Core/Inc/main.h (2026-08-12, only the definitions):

#define B1_Pin GPIO_PIN_13
#define B1_GPIO_Port GPIOC
#define LD2_Pin GPIO_PIN_5
#define LD2_GPIO_Port GPIOA
#define R_PWM_Pin GPIO_PIN_6
#define R_PWM_GPIO_Port GPIOA
#define L_PWM_Pin GPIO_PIN_7
#define L_PWM_GPIO_Port GPIOA
#define DIR1_Pin GPIO_PIN_11
#define DIR1_GPIO_Port GPIOA
#define DIR2_Pin GPIO_PIN_12
#define DIR2_GPIO_Port GPIOA
#define TMS_Pin GPIO_PIN_13
#define TMS_GPIO_Port GPIOA
#define TCK_Pin GPIO_PIN_14
#define TCK_GPIO_Port GPIOA
#define SWO_Pin GPIO_PIN_3
#define SWO_GPIO_Port GPIOB
#define SERVO_PWM_Pin GPIO_PIN_6
#define SERVO_PWM_GPIO_Port GPIOB

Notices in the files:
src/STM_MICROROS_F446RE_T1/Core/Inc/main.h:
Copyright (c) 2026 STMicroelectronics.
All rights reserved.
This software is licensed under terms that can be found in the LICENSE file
